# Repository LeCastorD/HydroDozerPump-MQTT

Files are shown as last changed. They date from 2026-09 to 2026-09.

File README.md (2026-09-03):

<div align="center">
  <h1>HydroDozerPump MQTT</h1>
  <p><strong>ESP8266 two-pump hydroponic dosing controller for Home Assistant</strong></p>
  <table>
    <tr>
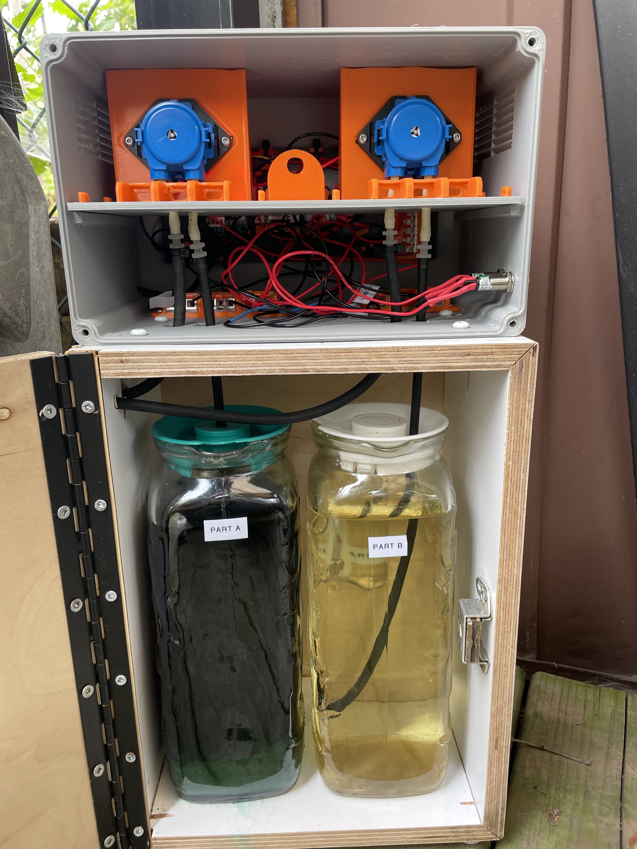
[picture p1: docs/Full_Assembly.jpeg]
Complete HydroDozerPump assembly with enclosure, two Kamoer pumps, and nutrient bottles
      <td align="center"><br><em>Complete HydroDozerPump assembly</em></td>
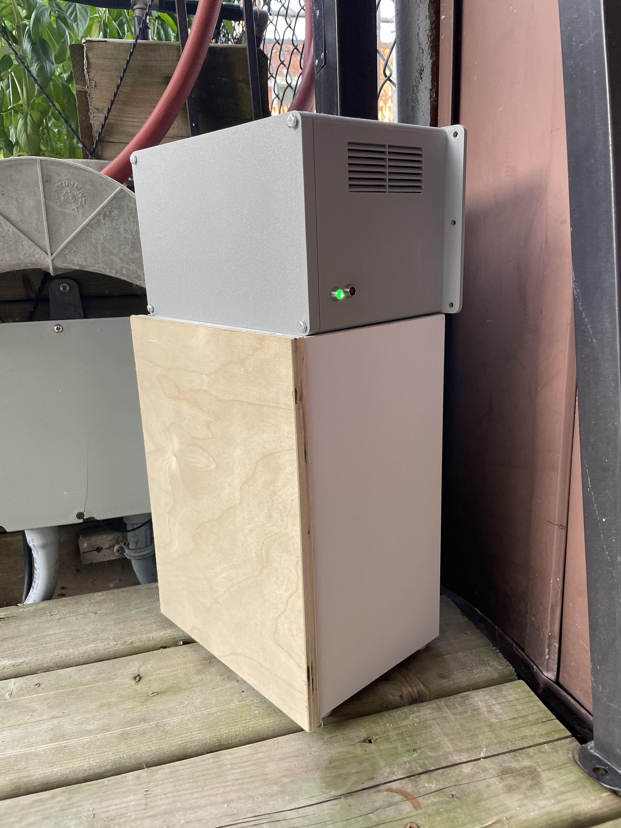
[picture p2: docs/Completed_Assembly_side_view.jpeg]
Side view of the completed HydroDozerPump enclosure with green and red status lights
      <td align="center"><br><em>Completed enclosure side view</em></td>
    </tr>
    <tr>
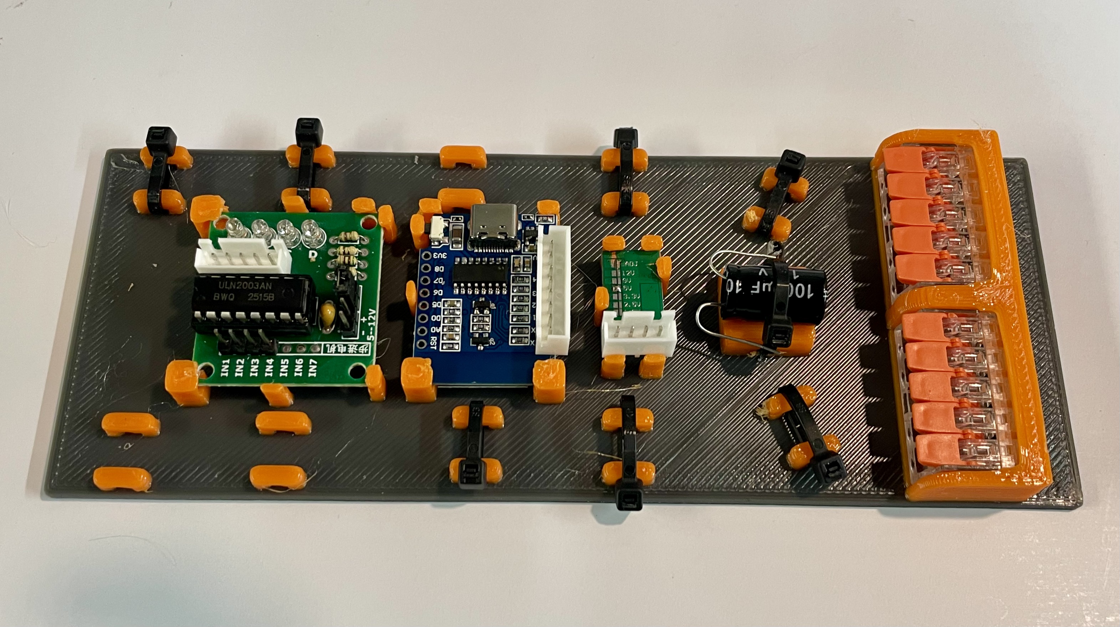
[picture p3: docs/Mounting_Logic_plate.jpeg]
Populated HydroDozerPump logic mounting plate with controller, ULN2003 board, and power terminals
      <td align="center"><br><em>Populated logic mounting plate</em></td>
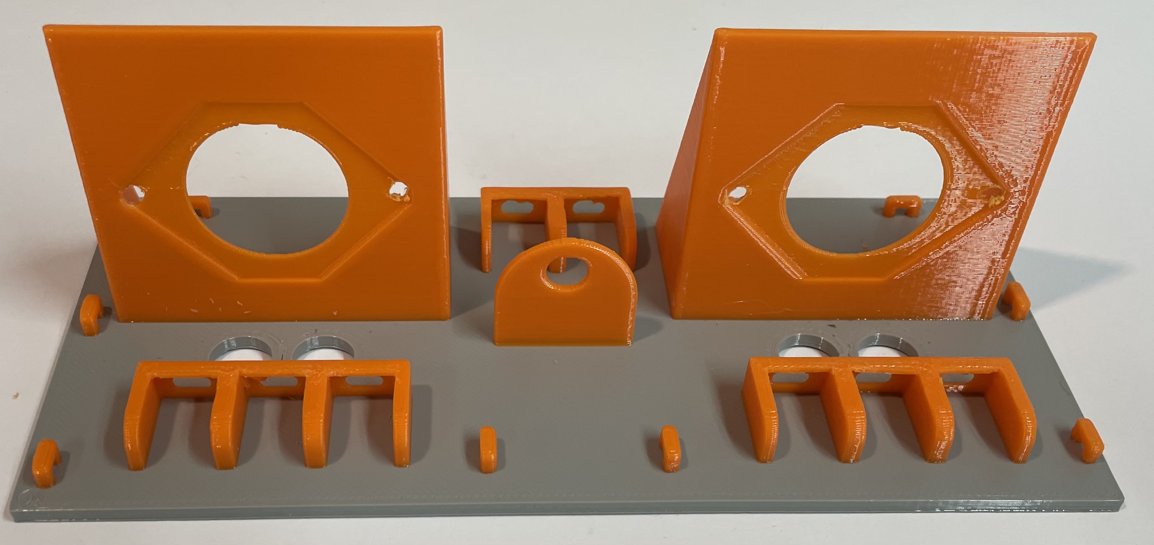
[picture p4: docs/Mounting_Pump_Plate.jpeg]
HydroDozerPump pump mounting plate and printed pump brackets
      <td align="center"><br><em>Pump mounting plate and brackets</em></td>
    </tr>
  </table>
  <p>
    <a href="#build-with-platformio">Build</a> |
    <a href="#wiring">Wiring</a> |
    <a href="#enclosure-and-assembly">Enclosure</a> |
    <a href="#first-setup">First setup</a>
  </p>
</div>

> Remaining image placeholder: the validated wiring drawing will be added after the reference image is available.

<h2 id="table-of-contents">Table of Contents</h2>

<ul>
  <li><a href="#overview">Overview</a></li>
  <li><a href="#typical-usage">Typical usage</a></li>
  <li><a href="#features">Features</a></li>
  <li><a href="#hardware">Hardware</a></li>
  <li><a href="#component-reference">Component reference</a></li>
  <li><a href="#device-naming">Device naming</a></li>
  <li><a href="#safety">Safety</a></li>
  <li><a href="#wiring">Wiring</a></li>
  <li><a href="#status-indicator-lights">Status indicator lights</a></li>
  <li><a href="#bill-of-materials">Bill of materials</a></li>
  <li><a href="#enclosure-and-assembly">Enclosure and assembly</a></li>
  <li><a href="#build-with-platformio">Build with PlatformIO</a></li>
  <li><a href="#upload-firmware">Upload firmware</a></li>
  <li><a href="#ota-upgrade">OTA upgrade and LittleFS data</a></li>
  <li><a href="#initial-wi-fi-configuration">Initial Wi-Fi configuration</a></li>
  <li><a href="#default-web-ui-login">Default Web UI login</a></li>
  <li><a href="#first-setup">First setup</a></li>
  <li><a href="#pump-calibration-and-dosing">Pump calibration and dosing</a></li>
  <li><a href="#web-ui-reference">Web UI reference</a></li>
  <li><a href="#home-assistant-interface">Home Assistant interface</a></li>
  <li><a href="#security">Security</a></li>
  <li><a href="#repository-layout">Repository layout</a></li>
  <li><a href="#license">License</a></li>
  <li><a href="#disclaimer">Disclaimer</a></li>
</ul>

<h2 id="overview">Overview</h2>

<p>HydroDozerPump is a two-channel hydroponic dosing controller built around a Wemos D1 Mini (ESP8266). It drives Pump A and Pump B through an external driver, tracks the remaining volume in two nutrient bottles, and publishes its state and controls through MQTT discovery for Home Assistant.</p>

<blockquote>
  <p><strong>Beta / experimental hardware:</strong> this project is in beta and the current enclosure does not provide the wet/dry separation planned for a production design. It does not claim compliance with <a href="https://www.ul.com/services/environmental-rated-accessories-enclosures">ANSI/UL 50E</a>, <a href="https://www.nema.org/docs/default-source/standards-document-library/nema-250-2018-contents-and-scope.pdf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">NEMA 250</a>, <a href="https://webstore.iec.ch/en/publication/2448">IEC 60529</a>, or, where applicable, <a href="https://docinfofiles.nfpa.org/files/AboutTheCodes/70/70_A2022_NEC_P07_FD_PIReport_rev_1005.pdf">ANSI/NFPA 70 (NEC), Article 547</a>.</p>
</blockquote>

<p>The controller supports manual doses, per-pump calibration, three daily scheduler slots, bottle refill tracking, pump-run logging, browser-based configuration, and OTA firmware updates. It is intended for low-voltage dosing hardware only; select and wire the pump power supply and driver for the exact pumps in the installation.</p>

<p><strong>Wi-Fi limitation:</strong> the ESP8266 supports 2.4 GHz 802.11 b/g/n Wi-Fi only. Use a compatible 2.4 GHz network for onboarding and normal operation.</p>

<h2 id="typical-usage">Typical usage</h2>

<ol>
  <li>Connect the controller to Wi-Fi, configure MQTT, and confirm that the MQTT Settings page reports a connection and Home Assistant discovers the device.</li>
  <li>Route each pump outlet to a safe test container, verify the flow direction, then calibrate Pump A and Pump B using the measured volume.</li>
  <li>Measure each nutrient container's usable volume and enter the capacity for the matching bottle in Home Assistant.</li>
  <li>Set the total daily dose and the Pump A/Pump B ratio, then schedule the three dosing times for the required photoperiod.</li>
  <li>Confirm the first doses and bottle-volume tracking, then refill and reset bottle volumes as needed.</li>
</ol>

<h2 id="features">Features</h2>

<ul>
  <li>Two independently controlled dosing pumps with active-high driver outputs</li>
  <li>Two tracked nutrient bottles with capacity, remaining volume, and low-bottle alarm state</li>
  <li>Per-pump flow calibration and measured-volume dosing</li>
  <li>Three daily scheduler slots with a pause control and a delay between Pump A and Pump B</li>
  <li>WiFiManager onboarding, DHCP or static network settings, and mDNS</li>
  <li>MQTT state publishing and Home Assistant MQTT discovery</li>
  <li>Web UI for configuration, calibration, backups, pump logs, and safe MQTT commands</li>
  <li>LittleFS storage for configuration and pump-run logs</li>
  <li>OTA firmware updates and a hardware factory-reset input</li>
</ul>

<h2 id="hardware">Hardware</h2>

<ul>
  <li>Wemos D1 Mini or compatible ESP8266 board</li>
  <li>Two Kamoer peristaltic dosing pumps</li>
  <li>ULN2003 driver board</li>
  <li>LMNIL-775P-12V-G and LMNIL-775P-12V-R 12 V panel-mount indicator lights</li>
  <li>Power supply sized for the controller and the selected pumps</li>
  <li>Enclosure, wiring, and connectors appropriate for the installation</li>
</ul>

<p>See <a href="docs/BOM.md">docs/BOM.md</a> for the current parts reference and items that still need model-specific confirmation.</p>

<h2 id="component-reference">Component reference</h2>

<p>The following generic reference photos show the controller, power, and wiring hardware used in this type of low-voltage enclosure build. Confirm the ratings and pin labels of the exact parts used in the installation.</p>

<table>
  <tr>
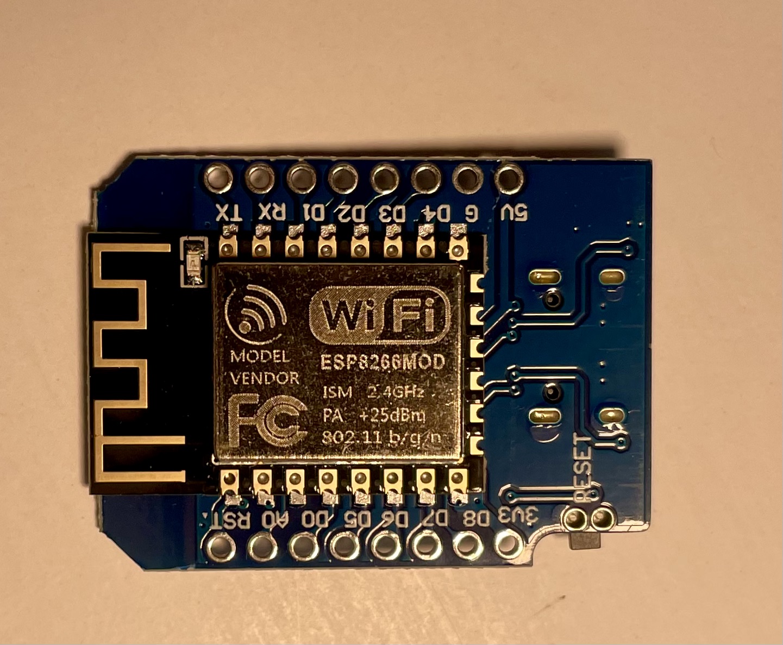
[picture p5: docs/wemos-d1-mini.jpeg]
Wemos D1 Mini ESP8266 controller board
    <td align="center"><br><em>Wemos D1 Mini controller</em></td>
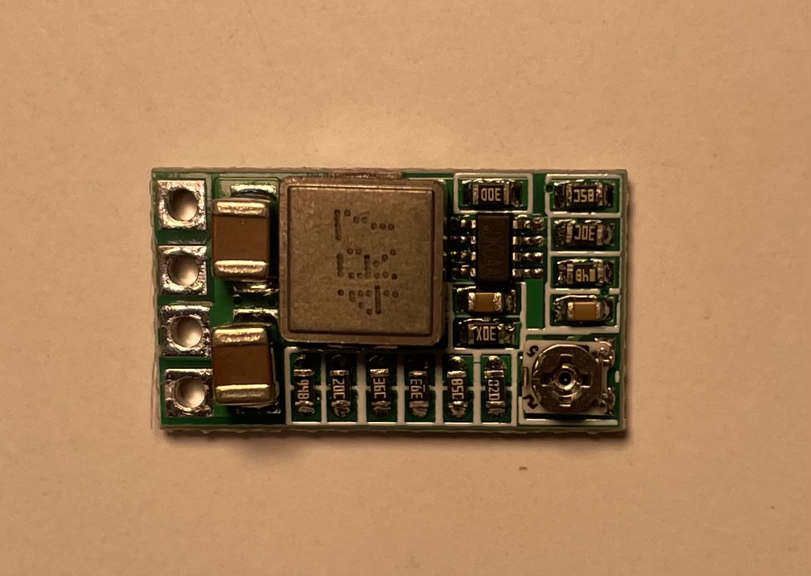
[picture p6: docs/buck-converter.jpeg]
Compact adjustable DC buck converter
    <td align="center"><br><em>Example DC buck converter</em></td>
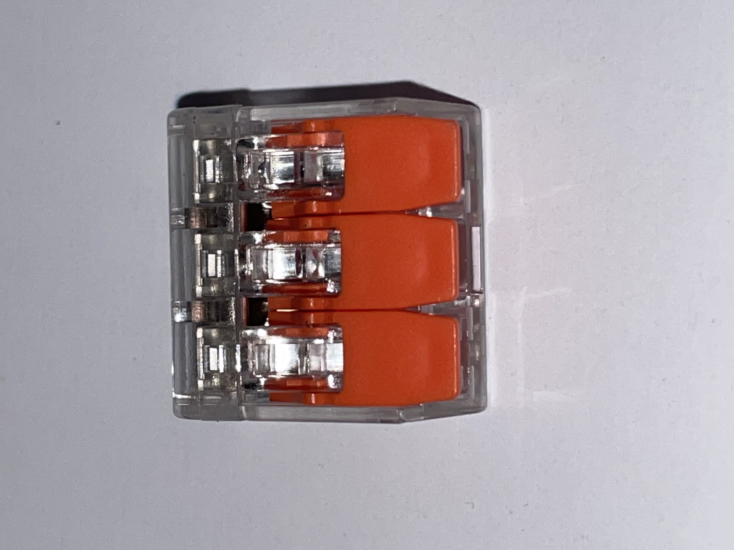
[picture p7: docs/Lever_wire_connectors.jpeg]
Three-position lever wire connector
    <td align="center"><br><em>Lever wire connector</em></td>
  </tr>
  <tr>
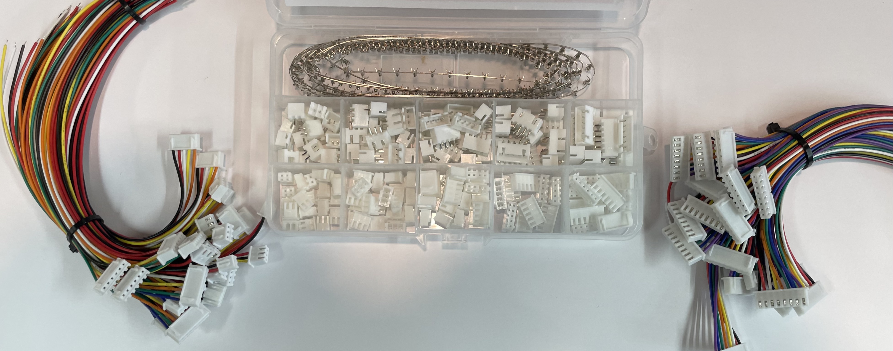
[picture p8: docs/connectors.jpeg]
Connector housings, crimp terminals, and prewired leads
    <td align="center"><br><em>Connector kit and prewired leads</em></td>
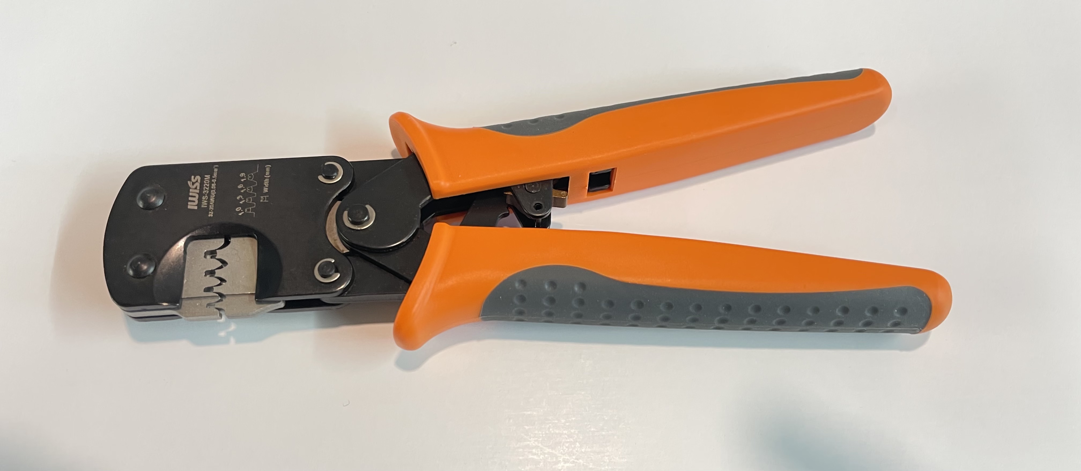
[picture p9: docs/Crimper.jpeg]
Crimping tool for small connector terminals
    <td align="center"><br><em>Crimping tool</em></td>
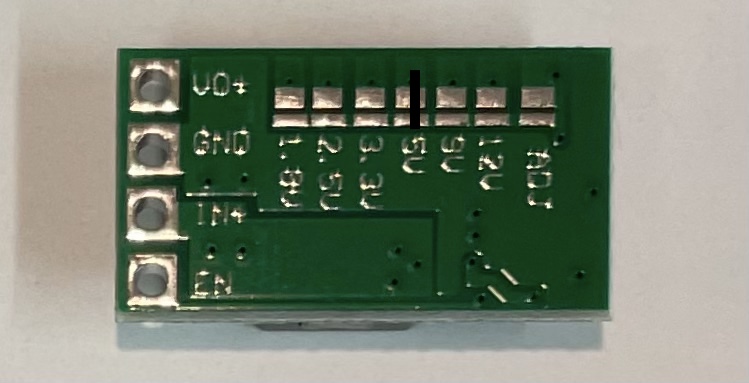
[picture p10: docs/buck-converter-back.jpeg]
Rear view of an example buck converter board
    <td align="center"><br><em>Example buck-converter board layout</em></td>
  </tr>
  <tr>
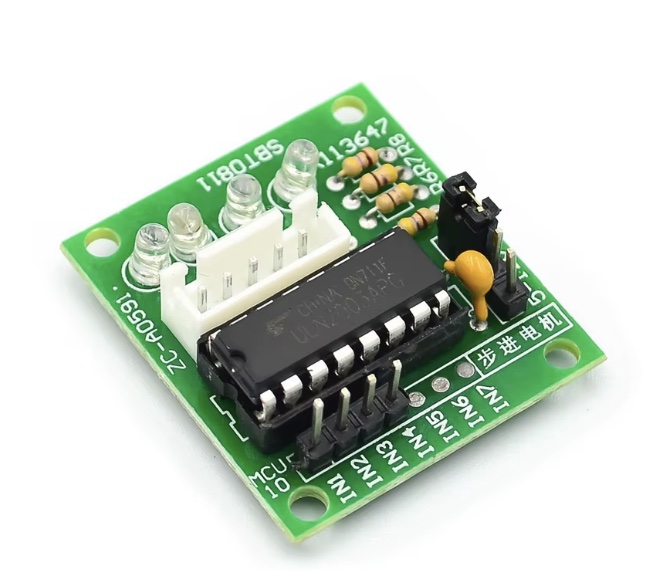
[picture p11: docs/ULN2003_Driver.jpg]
ULN2003 driver board
    <td align="center"><br><em>ULN2003 driver board</em></td>
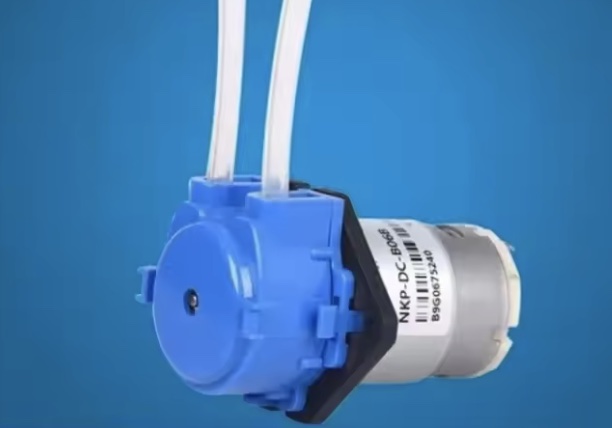
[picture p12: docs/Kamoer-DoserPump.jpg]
Kamoer peristaltic dosing pump with tubing
    <td align="center" colspan="2"><br><em>Kamoer peristaltic dosing pump</em></td>
  </tr>
  <tr>
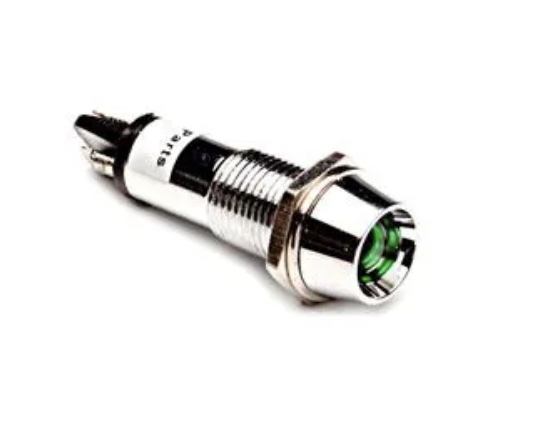
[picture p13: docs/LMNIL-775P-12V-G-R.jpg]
LMNIL-775P-12V green and red panel-mount indicator lights
    <td align="center" colspan="3"><br><em>LMNIL-775P-12V-G / LMNIL-775P-12V-R 12 V status lights</em></td>
  </tr>
</table>

<h2 id="device-naming">Device naming</h2>

<p>When no custom name is saved, the firmware derives a unique identity from the last two bytes of the ESP8266 Wi-Fi MAC address. The generated name uses the form <code>hydrodozerpump-XXXX</code>, where <code>XXXX</code> is a lowercase hexadecimal suffix. The MQTT client ID uses <code>HydroDozerPump-XXXX</code>.</p>

<p>A custom hostname can be saved from <strong>Settings &gt; Networking</strong>. It becomes the Wi-Fi hostname, mDNS hostname (<code>http://&lt;device-name&gt;.local</code>), and the node segment used in the HydroDozerPump MQTT topic tree. The firmware normalizes non-alphanumeric characters in the MQTT node segment to hyphens.</p>

<h2 id="safety">Safety</h2>

<ul>
  <li>Never power a pump or status light from an ESP8266 GPIO pin. Use the ULN2003 driver and a supply sized for every connected load.</li>
  <li>Connect the ESP8266, ULN2003 board, and load power-supply grounds together so the control signals have a common reference.</li>
  <li>Verify pump polarity, driver input logic, tubing, and flow direction with pumps disconnected from nutrient bottles before normal dosing.</li>
  <li>Calibrate each pump with the actual tubing and liquid. Dose accuracy depends on the installed pump, tubing, fluid viscosity, and supply voltage.</li>
  <li>Keep a manual way to stop pump power during commissioning. The firmware hard maximum is not a replacement for safe hardware design and supervision.</li>
</ul>

<h2 id="wiring">Wiring</h2>

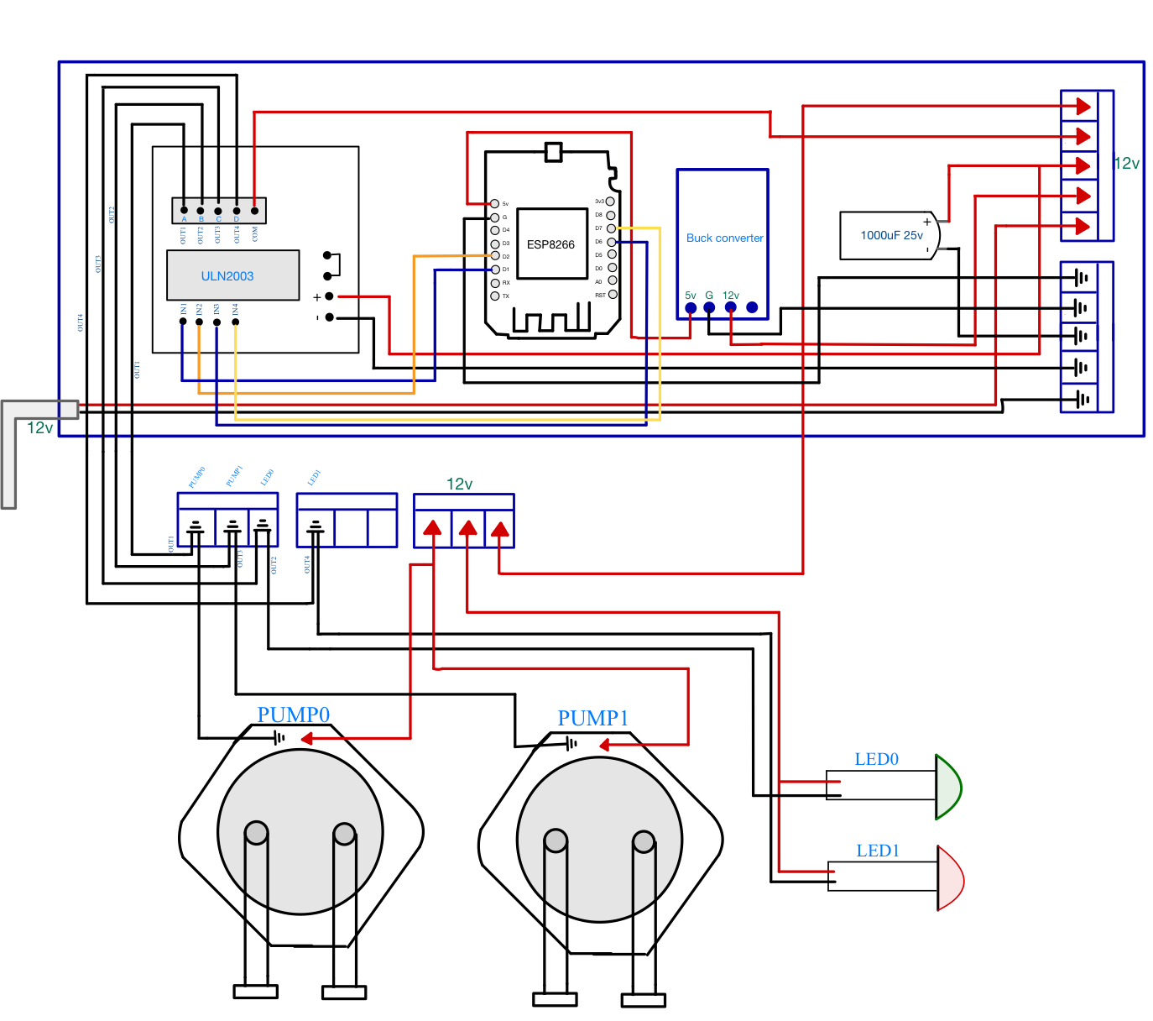
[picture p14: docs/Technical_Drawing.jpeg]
HydroDozerPump technical wiring drawing
<p align="center"><br><em>HydroDozerPump technical wiring reference</em></p>

<table>
  <thead><tr><th>Controller pin</th><th>Connection</th></tr></thead>
  <tbody>
    <tr><td><code>D1</code> / <code>GPIO5</code></td><td>INT1 (<em>ULN2003</em>)</td></tr>
    <tr><td><code>D2</code> / <code>GPIO4</code></td><td>INT2 (<em>ULN2003</em>)</td></tr>
    <tr><td><code>D6</code> / <code>GPIO12</code></td><td>INT3 (<em>ULN2003</em>)</td></tr>
    <tr><td><code>D7</code> / <code>GPIO13</code></td><td>INT1 (<em>ULN2003</em>)</td></tr>
    <tr><td><code>D5</code> / <code>GPIO14</code></td><td>Factory-reset jumper input; short to <code>GND</code> during boot for at least three seconds</td></tr>
    <tr><td><code>GND</code></td><td>Common ground between the ESP8266, ULN2003 board, pumps, status lights, and power supply</td></tr>
  </tbody>
</table>

<p>The firmware assumes active-high pump-driver inputs: <code>HIGH</code> turns a pump on and <code>LOW</code> turns it off. The two status-light outputs are also active-high and use PWM for dimming/pulsing. Change <code>PUMP_ACTIVE_HIGH</code> or <code>STATUS_LED_ACTIVE_HIGH</code> in <a href="src/HydroDozerPump/main.cpp">src/HydroDozerPump/main.cpp</a> only if the installed wiring uses inverted logic. See <a href="docs/hardware-pinout.md">docs/hardware-pinout.md</a> for electrical notes and the recovery-jumper procedure.</p>

<h2 id="status-indicator-lights">Status indicator lights</h2>

<p>The green light is connected through the ULN2003 from <code>D6</code>; the red light is connected from <code>D7</code>.</p>

<table>
  <thead><tr><th>Green</th><th>Red</th><th>State and meaning</th></tr></thead>
  <tbody>
    <tr><td align="center">🟢<br>Solid</td><td align="center">⚫<br>Off</td><td><strong>Normal / idle:</strong> the controller is ready and no pump is currently running.</td></tr>
    <tr><td align="center">🟢<br>Pulsing</td><td align="center">⚫<br>Off</td><td><strong>Pumping:</strong> the green indicator pulses while Pump A or Pump B is running.</td></tr>
    <tr><td align="center">🟢<br>Solid or pulsing</td><td align="center">🔴<br>Solid</td><td><strong>Low bottle:</strong> red turns on when either bottle reaches the configured threshold. Green stays solid while idle and continues pulsing if a pump is running.</td></tr>
    <tr><td align="center">🟢<br>Alternating</td><td align="center">🔴<br>Alternating</td><td><strong>Dosing halted:</strong> green and red alternate every 350 ms when the scheduler is paused or a bottle is empty. Refill the bottle and resume the scheduler before dosing.</td></tr>
  </tbody>
</table>

<p><strong>Priority:</strong> the paused/empty alternating state overrides the normal, pumping, and low-bottle displays.</p>

<h2 id="bill-of-materials">Bill of materials</h2>

<p>See <a href="docs/BOM.md">docs/BOM.md</a> for the electronics, pump-control hardware, wiring, and enclosure parts list.</p>

<h2 id="enclosure-and-assembly">Enclosure and assembly</h2>

<h3>First beta enclosure notice</h3>

<p><strong>This is the first beta release of the mounting and enclosure design.</strong> It is a work in progress. In this revision, the pumps, tubing, and nutrient bottles (the wet side) share the same overall enclosure assembly as the controller, ULN2003 driver, and wiring (the electronics side). It does not provide a tested liquid-tight physical barrier between those areas.</p>

<p>Do not describe this prototype as water-resistant, IP rated, NEMA rated, certified, or compliant with an electrical-enclosure standard. Do not use it unattended or where a leak, condensation, splash, or service activity could reach electronics. Disconnect power before filling bottles, changing tubing, or servicing a pump.</p>

<p>The next enclosure revision is intended to separate the wet side from the electronics using a physical bulkhead and independently managed cable/tube pass-throughs. The finished design will need to be evaluated and tested against the environment and installation requirements that apply to its actual use.</p>

<h3>Standards and design references</h3>

<ul>
  <li><a href="https://www.ul.com/services/environmental-rated-accessories-enclosures">ANSI/UL 50E</a>: environmental considerations for electrical equipment enclosures, including maintaining an environmental seal.</li>
  <li><a href="https://www.nema.org/docs/default-source/standards-document-library/nema-250-2018-contents-and-scope.pdf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">NEMA 250</a>: enclosure types and environmental protection for electrical equipment up to 1000 V.</li>
  <li><a href="https://webstore.iec.ch/en/publication/2448">IEC 60529</a>: IP Code classification for protection provided by electrical enclosures against ingress.</li>
  <li><a href="https://docinfofiles.nfpa.org/files/AboutTheCodes/70/70_A2022_NEC_P07_FD_PIReport_rev_1005.pdf">ANSI/NFPA 70 (NEC), Article 547</a>: relevant where the installation is in an agricultural-building area subject to wet, damp, corrosive, or wash-down conditions.</li>
</ul>

<p>These references do not create a blanket rule that every hydroponic enclosure must use one particular barrier. They establish enclosure-performance and installation expectations; a physical wet/dry separation is the safety approach planned for the next revision. Consult the authority having jurisdiction and a qualified electrical professional for any permanent or mains-connected installation.</p>

<p>The repository includes the current 3MF files:</p>

<ul>
  <li><a href="Enclosure%20and%20mount/Enclosure_Box.3mf">Enclosure_Box.3mf</a></li>
  <li><a href="Enclosure%20and%20mount/Mounting_Llogic_plate.3mf">Mounting_Llogic_plate.3mf</a></li>
  <li><a href="Enclosure%20and%20mount/Mounting_Pump_Plate.3mf">Mounting_Pump_Plate.3mf</a></li>
</ul>

<p>Confirm printed clearances, hardware sizes, pump dimensions, and electrical isolation against the exact components before printing or assembling the enclosure.</p>

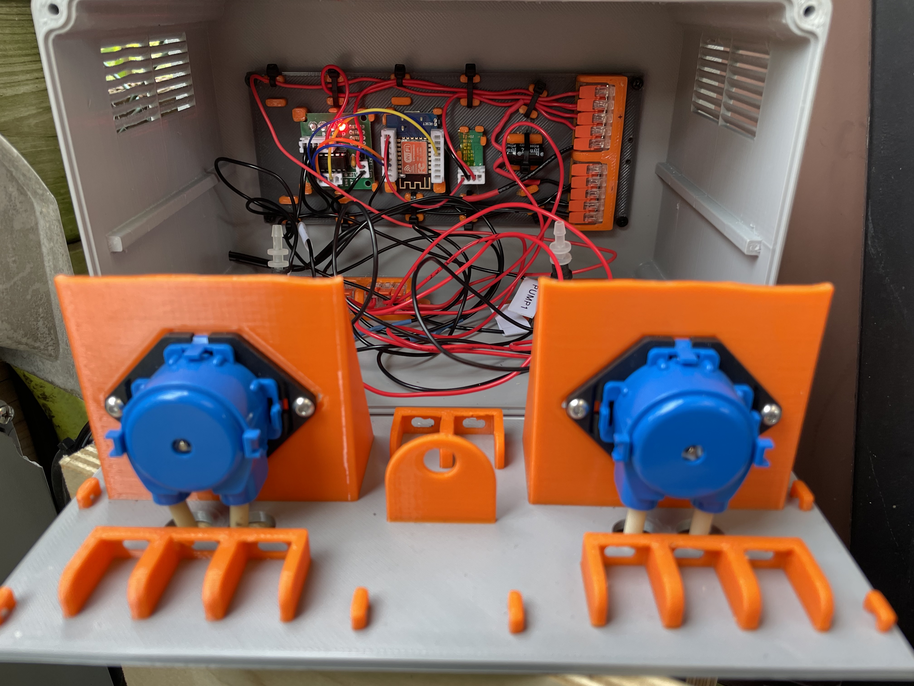
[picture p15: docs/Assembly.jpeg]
HydroDozerPump enclosure assembly with two Kamoer pumps, mounting plates, terminals, and tubing connections
<p align="center"><br><em>Enclosure assembly reference</em></p>

<h2 id="build-with-platformio">Build with PlatformIO</h2>

<h3>Requirements</h3>

<ul>
  <li>VS Code with the PlatformIO extension, or PlatformIO CLI</li>
  <li>A Wemos D1 Mini connected by USB</li>
  <li>The dependencies listed in <a href="platformio.ini">platformio.ini</a></li>
</ul>

<pre><code>pio run</code></pre>

<p>The build target is <code>WEMOS_D1_Mini</code>. The pre-build script updates <code>include/fw_version_auto.h</code>.</p>

<h2 id="upload-firmware">Upload firmware</h2>

<p>Replace <code>&lt;PORT&gt;</code> with the serial port assigned to the board:</p>

<pre><code>pio run -t upload --upload-port &lt;PORT&gt;
pio run -t uploadfs --upload-port &lt;PORT&gt;</code></pre>

<p>The first command uploads the firmware. The second uploads the LittleFS web interface and filesystem data stored in <code>data/web/</code>.</p>

<h2 id="ota-upgrade">OTA upgrade and LittleFS data</h2>

<p><strong>Important:</strong> firmware and LittleFS are separate flash areas. A firmware-only OTA update normally preserves the saved configuration and pump log. Uploading a LittleFS image replaces the filesystem, including <code>/config.json</code> and <code>/pump_runs.csv</code>.</p>

<ol>
  <li>Before any LittleFS upload, download <code>config.json</code> and <code>pump_runs.csv</code> from <strong>Settings &gt; Backup &amp; Restore</strong>.</li>
  <li>For a firmware-only OTA update, sign in to the Web UI and open <code>/update</code>. Upload only the firmware <code>.bin</code>, then verify that MQTT reconnects.</li>
  <li>After a LittleFS upload, restore the backed-up <code>config.json</code> and reboot the controller. Restore <code>pump_runs.csv</code> separately if its history is needed.</li>
  <li>If no backup is restored, configure the controller again, including Wi-Fi, network name, MQTT settings, time zone, credentials, bottle capacities, pump flow values, and scheduler settings.</li>
</ol>

<h2 id="initial-wi-fi-configuration">Initial Wi-Fi configuration</h2>

<p>This project uses <a href="https://github.com/tzapu/WiFiManager">WiFiManager</a> so Wi-Fi credentials are not hard-coded in the firmware.</p>

<ol>
  <li>Power the device with no saved Wi-Fi credentials, or clear them using a factory reset.</li>
  <li>Connect a phone or computer to the temporary access point named <code>HydroDozerPump-Setup</code>.</li>
  <li>Complete the WiFiManager captive portal and save the local 2.4 GHz network credentials.</li>
  <li>After the controller joins the network, open its assigned IP address or mDNS hostname, such as <code>http://hydrodozerpump-ab12.local</code>.</li>
</ol>

<h2 id="default-web-ui-login">Default Web UI login</h2>

<p>The initial Web UI and OTA credentials are case-sensitive:</p>

<table>
  <tr><th>Username</th><td><code>admin</code></td></tr>
  <tr><th>Password</th><td><code>adminpass</code></td></tr>
</table>

<p>Open <code>http://&lt;device-ip&gt;/login</code> when Web UI login is required. Change these values immediately at <strong>Settings &gt; OTA Settings</strong>; the same credentials control both the Web UI login and the <code>/update</code> OTA page. See <a href="docs/security.md">docs/security.md</a>.</p>

<h2 id="first-setup">First setup</h2>

<ol>
  <li><strong>Upload the firmware and Web UI:</strong> upload the firmware, then upload the LittleFS image so the files in <code>data/web/</code> are available on the controller.</li>
  <li><strong>Connect to Wi-Fi:</strong> follow <a href="#initial-wi-fi-configuration">Initial Wi-Fi configuration</a> when no Wi-Fi credentials are saved.</li>
  <li><strong>Set network and time:</strong> in <strong>Settings &gt; Networking</strong>, set the hostname and choose DHCP or static addressing. In <strong>Settings &gt; Time Synchronization</strong>, apply the correct POSIX time-zone string. Accurate time is required for the daily scheduler.</li>
  <li><strong>Secure the device:</strong> replace the Web UI/OTA credentials in <strong>Settings &gt; OTA Settings</strong> and replace the public MQTT defaults in <strong>Settings &gt; MQTT Settings</strong>.</li>
  <li><strong>Connect MQTT:</strong> configure the broker, port, client ID, and a dedicated MQTT account. Confirm that the MQTT page reports a connected state.</li>
  <li><strong>Configure the dosing system:</strong> set bottle capacities, calibrate each pump, set the low-bottle alarm, and configure the schedule before enabling normal dosing.</li>
  <li><strong>Verify Home Assistant:</strong> confirm the MQTT-discovered HydroDozerPump device and controls appear in Home Assistant. The topic contract is documented in <a href="docs/mqtt-contract-v1.md">docs/mqtt-contract-v1.md</a>.</li>
</ol>

<h2 id="pump-calibration-and-dosing">Pump calibration and dosing</h2>

<p>The controller starts with a nominal pump flow of <code>0.9 mL/s</code>; this is only a starting point. Use <strong>Pump Calibration</strong> to run a fixed-duration test, measure the volume dispensed, and save the result for each pump. Recalibrate after changing a pump, tube, liquid, or supply voltage.</p>

<p>The scheduler divides the configured total daily volume across three time slots. Pump A runs first; when both pumps are needed, Pump B runs after the configured safety gap. The scheduler requires valid synchronized time and can be paused from Home Assistant. Bottle volume is reduced after allowed doses and can be reset to the configured capacity using the refill actions.</p>

<h2 id="web-ui-reference">Web UI reference</h2>

> The screenshots below use generic, public-safe example values. Do not publish a device backup or screenshot containing private credentials, hostnames, or network addresses.

<p>The home page provides access to Pump Calibration, Setup, MQTT command sending, Pump Log, Firmware Upgrade, and reboot. The complete route map is maintained in <a href="docs/web-pages-index.md">docs/web-pages-index.md</a>.</p>

<table>
  <tr>
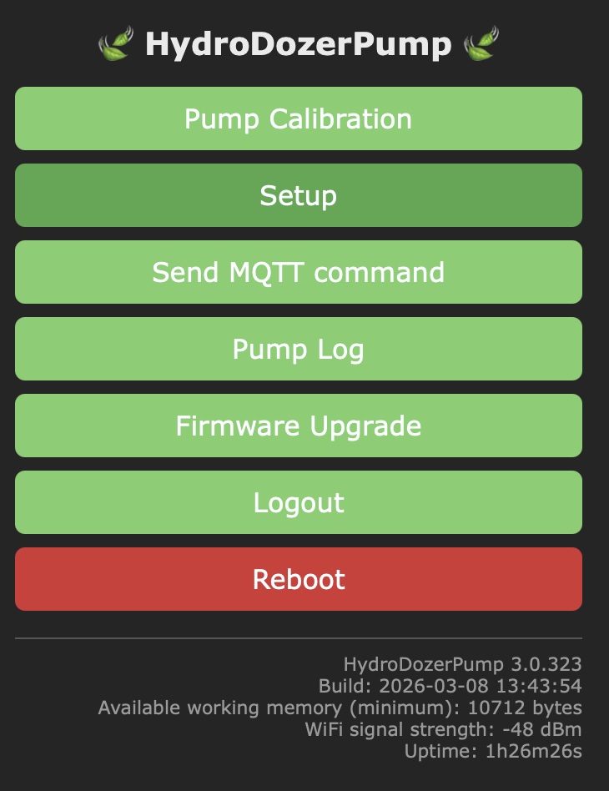
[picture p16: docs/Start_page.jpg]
HydroDozerPump Web UI start page
    <td align="center"><br><em>HydroDozerPump Web UI start page</em></td>
  </tr>
</table>

<h3>Pump calibration</h3>

<p>Select <strong>Calibration Pump A</strong> or <strong>Calibration Pump B</strong> to run that pump for 60 seconds. After it stops, measure the dispensed liquid, enter the measured volume in mL, and select <strong>Apply</strong>. This stores the measured flow rate for future manual and scheduled doses.</p>

<table>
  <tr>
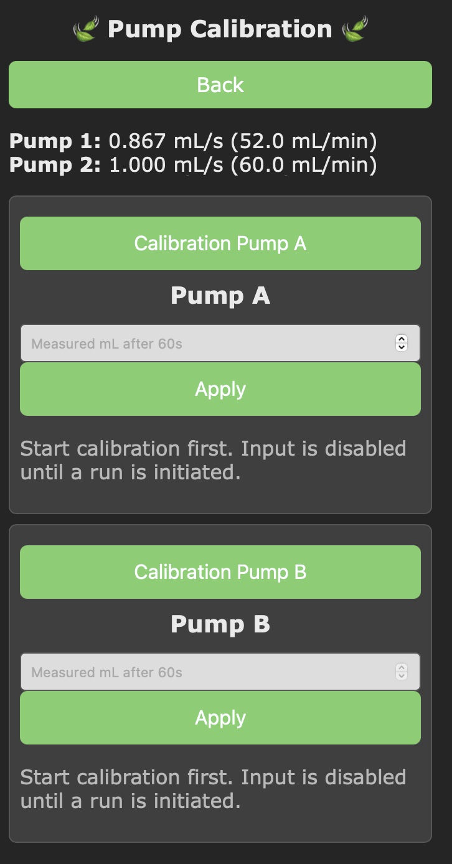
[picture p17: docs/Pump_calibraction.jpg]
HydroDozerPump pump calibration page
    <td align="center"><br><em>Pump calibration for Pump A and Pump B</em></td>
  </tr>
</table>

<h3>Backup and restore</h3>

<p><strong>Download config.json</strong> saves the device configuration, while <strong>Download pump_runs.csv</strong> saves the dosing log. Restore each file only to the matching restore control. A restored <code>config.json</code> can contain credentials, so keep backups private; reboot after restoring configuration. A restored pump log must preserve its CSV header.</p>

<table>
  <tr>
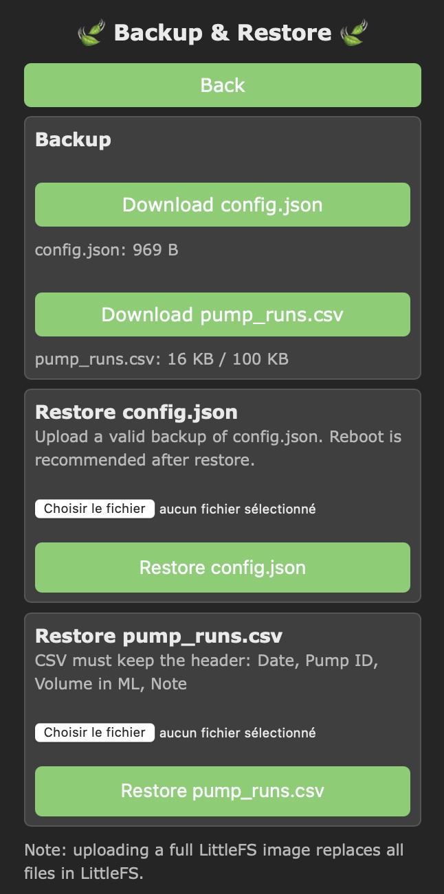
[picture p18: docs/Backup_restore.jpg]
HydroDozerPump backup and restore page
    <td align="center"><br><em>Configuration and pump-log backup and restore</em></td>
  </tr>
</table>

<h3>Pump log</h3>

<p>The pump-log page summarizes the three scheduler slots and shows the newest pump-run entries first. Use <strong>Download Pump Log</strong> to save the CSV file, and <strong>Refresh</strong> to reload the current entries. The log uses the columns <code>Date</code>, <code>Pump ID</code>, <code>Volume in ML</code>, and <code>Note</code>.</p>

<table>
  <tr>
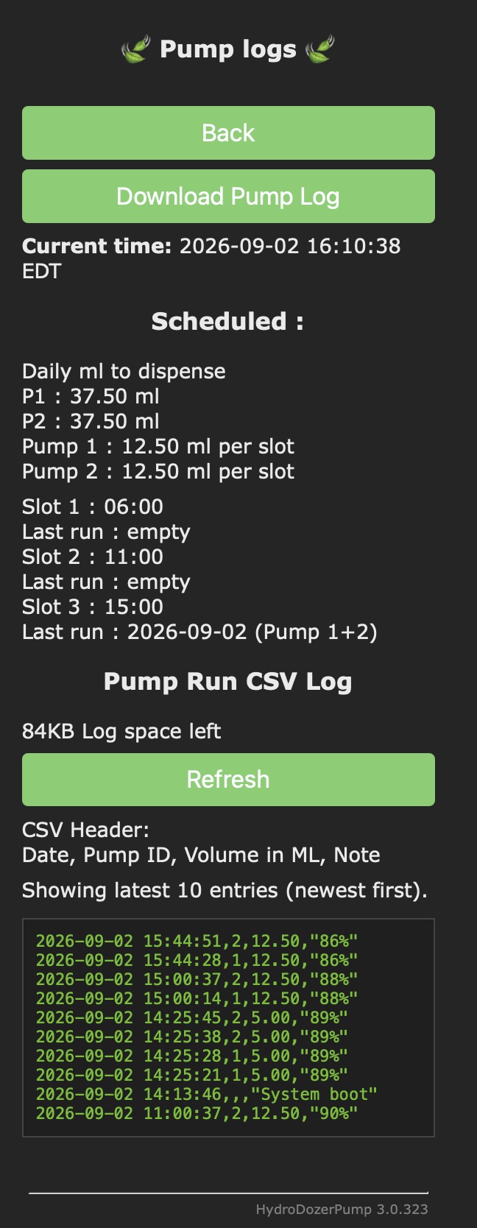
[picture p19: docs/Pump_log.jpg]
HydroDozerPump pump log page
    <td align="center"><br><em>Pump schedule summary and CSV pump-run log</em></td>
  </tr>
</table>

<h3>Firmware upgrade</h3>

<p>Select <strong>Firmware</strong> in the ElegantOTA page to upload the compiled firmware <code>.bin</code>. Select <strong>Filesystem</strong> only when uploading the LittleFS image; it replaces the Web UI and stored files, so back up <code>config.json</code> and <code>pump_runs.csv</code> first.</p>

<table>
  <tr>
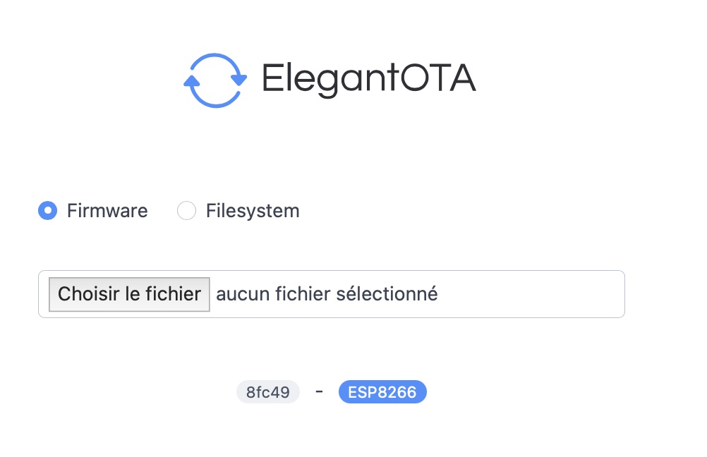
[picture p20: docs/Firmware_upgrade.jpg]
ElegantOTA firmware and filesystem upload page
    <td align="center"><br><em>Firmware and LittleFS upload page</em></td>
  </tr>
</table>

<h3>Send MQTT command</h3>

<p>The sender accepts only the templates shown below and validates the JSON before processing it. Scheduler and capacity templates publish to <code>hydrodozerpump/&lt;node&gt;/ha/cmd</code>; refill templates publish to <code>hydrodozerpump/&lt;node&gt;/cmd</code>. Commands are non-retained. If MQTT is disconnected, a valid command is applied locally and is not published.</p>

<table>
  <tr>
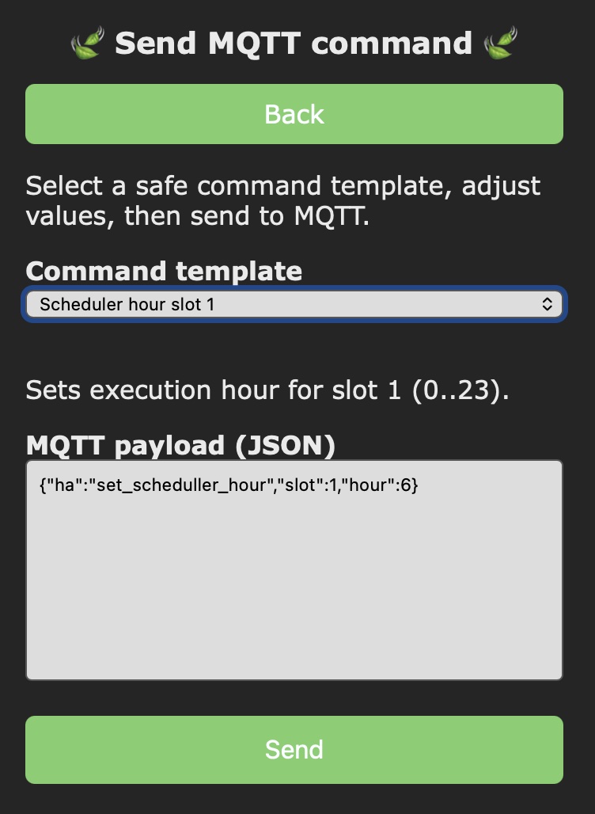
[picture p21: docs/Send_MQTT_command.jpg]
HydroDozerPump Send MQTT command page
    <td align="center"><br><em>Safe MQTT command sender</em></td>
  </tr>
</table>

<table>
  <thead>
    <tr><th>Template</th><th>Accepted value</th><th>Effect</th></tr>
  </thead>
  <tbody>
    <tr><td>Daily total mL</td><td>Positive mL, up to the current safe maximum</td><td>Sets the total liquid scheduled for the day, divided across the three daily slots.</td></tr>
    <tr><td>Part A ratio</td><td>0-100%</td><td>Sets Pump A's share of the daily total and automatically adjusts Part B to make 100%.</td></tr>
    <tr><td>Part B ratio</td><td>0-100%</td><td>Sets Pump B's share of the daily total and automatically adjusts Part A to make 100%.</td></tr>
    <tr><td>Scheduler pause</td><td><code>1</code> pause; <code>0</code> resume</td><td>Stops or resumes scheduled dosing. It does not change the saved schedule.</td></tr>
    <tr><td>Low Bottle Alarm</td><td>0-100%</td><td>Sets the percentage at or below which the low-bottle alarm and red indicator are activated.</td></tr>
    <tr><td>Scheduler hour slot 1</td><td>Hour 0-23</td><td>Sets the execution hour for the first daily dose slot.</td></tr>
    <tr><td>Scheduler hour slot 2</td><td>Hour 0-23</td><td>Sets the execution hour for the second daily dose slot.</td></tr>
    <tr><td>Scheduler hour slot 3</td><td>Hour 0-23</td><td>Sets the execution hour for the third daily dose slot.</td></tr>
    <tr><td>Bottle 1 capacity</td><td>More than 0 and up to 10,000 mL</td><td>Sets Bottle A's capacity. Remaining volume is capped at the new capacity when necessary.</td></tr>
    <tr><td>Bottle 2 capacity</td><td>More than 0 and up to 10,000 mL</td><td>Sets Bottle B's capacity. Remaining volume is capped at the new capacity when necessary.</td></tr>
    <tr><td>Refill Bottle A</td><td>No value</td><td>Sets Bottle A's remaining volume to its configured capacity.</td></tr>
    <tr><td>Refill Bottle B</td><td>No value</td><td>Sets Bottle B's remaining volume to its configured capacity.</td></tr>
  </tbody>
</table>

<h3>MQTT discovery and Home Assistant</h3>

<p>With MQTT discovery enabled, Home Assistant automatically exposes HydroDozerPump controls, bottle information, configuration, and diagnostics. The detailed views below use public-safe example network values.</p>

<table>
  <tr>
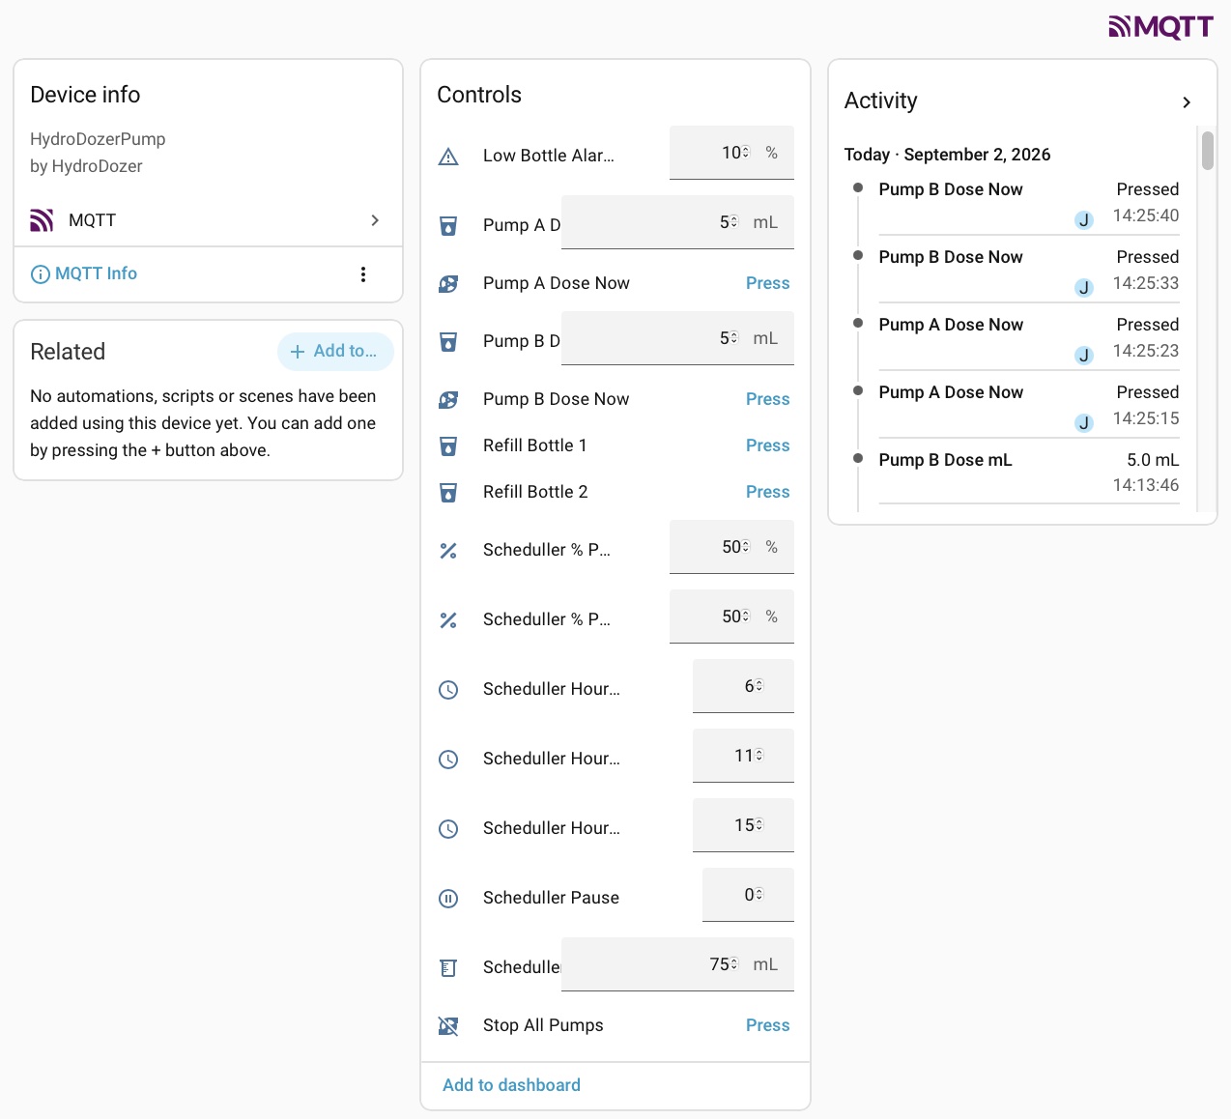
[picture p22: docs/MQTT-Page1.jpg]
Home Assistant MQTT discovery controls for HydroDozerPump
    <td align="center"><br><em>Home Assistant MQTT discovery: controls</em></td>
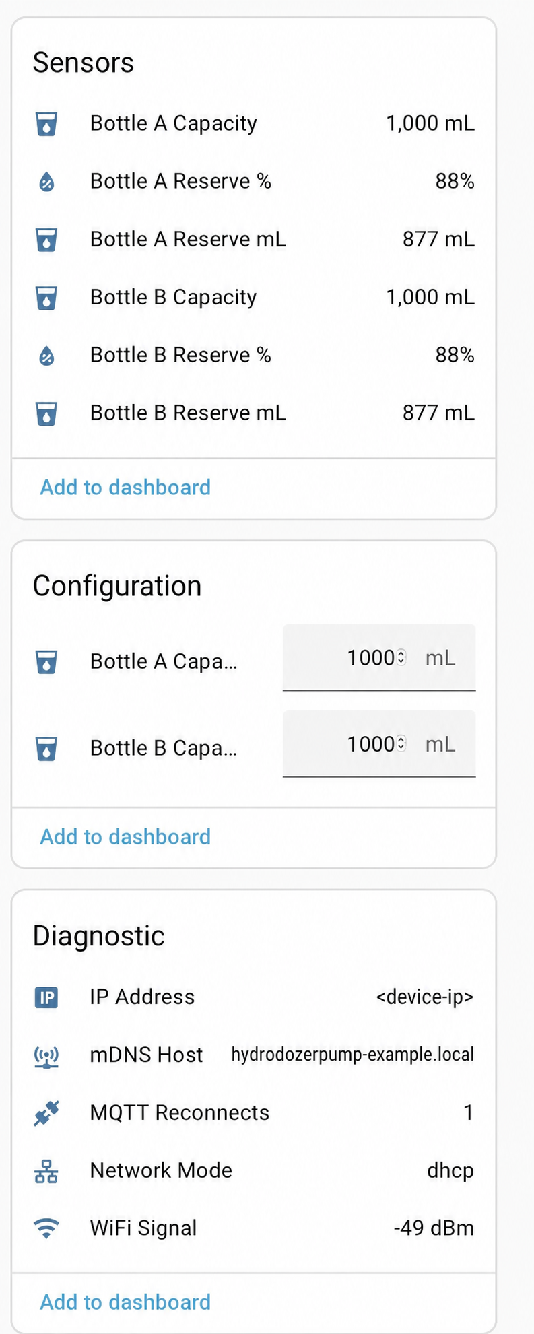
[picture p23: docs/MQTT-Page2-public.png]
Redacted Home Assistant MQTT discovery details for HydroDozerPump
    <td align="center"><br><em>Home Assistant MQTT discovery: configuration and diagnostics</em></td>
  </tr>
  <tr>
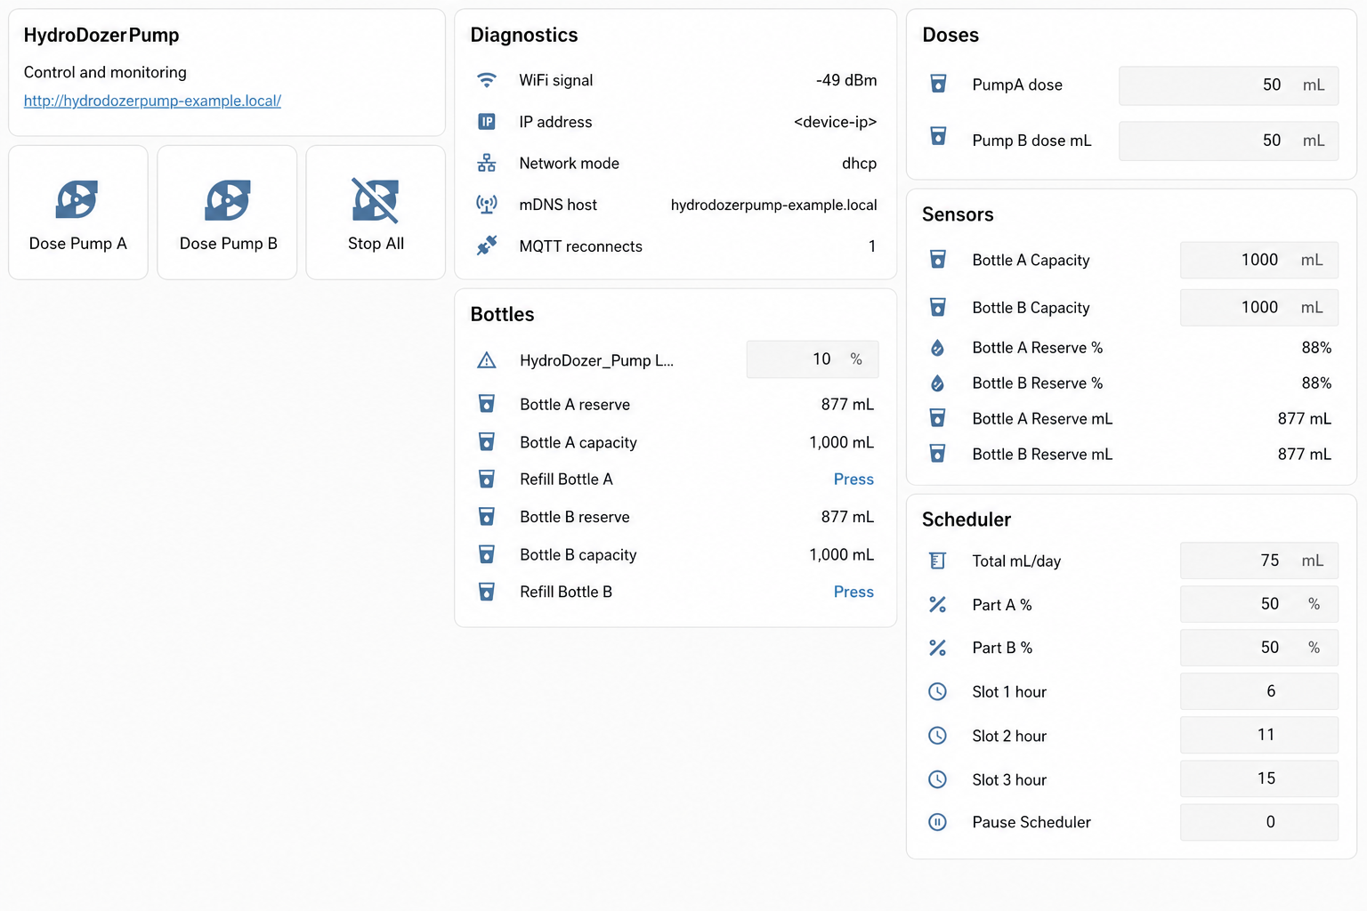
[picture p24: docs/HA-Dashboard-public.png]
Redacted example Home Assistant dashboard for HydroDozerPump
    <td align="center" colspan="2"><br><em>Example HydroDozerPump Home Assistant dashboard</em></td>
  </tr>
</table>

<h3>Network, MQTT, and recovery settings</h3>

<table>
  <tr>
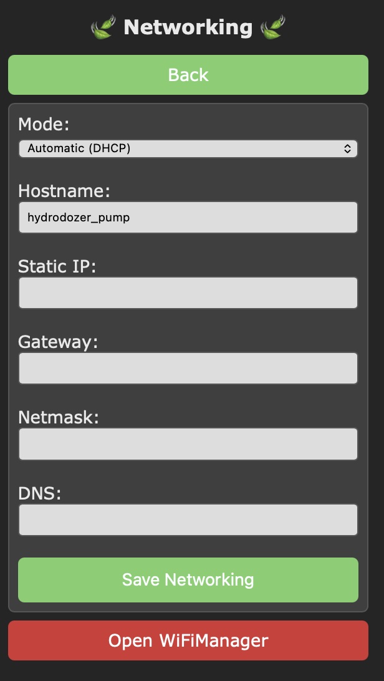
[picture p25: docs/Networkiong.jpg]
HydroDozerPump network settings page
    <td align="center"><br><em>Network settings: DHCP, hostname, and optional static address</em></td>
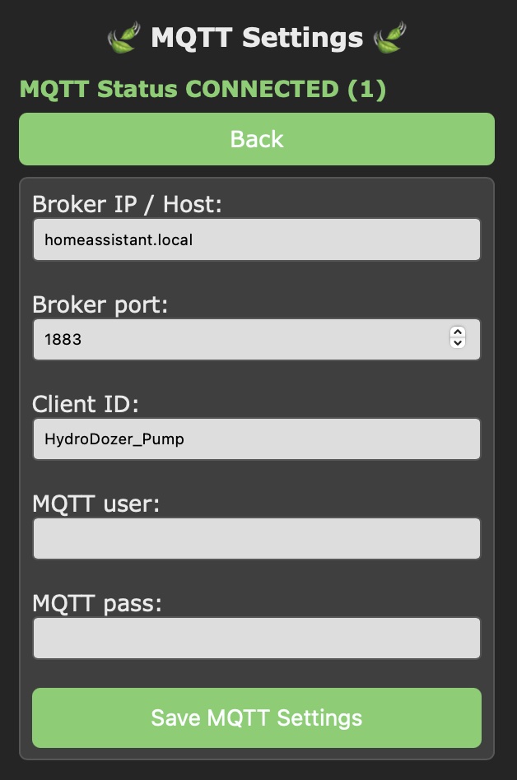
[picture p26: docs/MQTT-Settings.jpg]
HydroDozerPump MQTT settings page
    <td align="center"><br><em>MQTT broker and client settings</em></td>
  </tr>
  <tr>
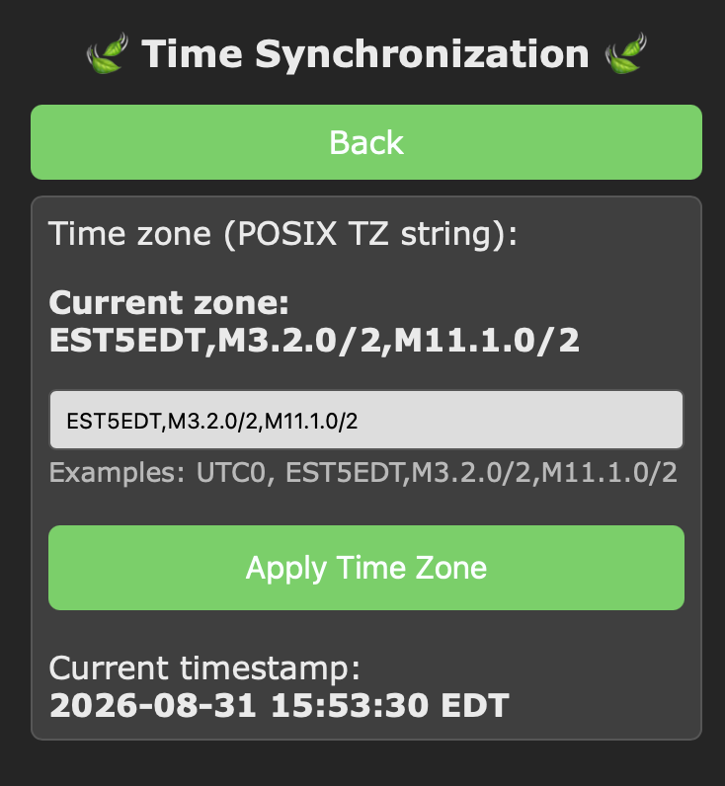
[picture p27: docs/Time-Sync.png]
HydroDozerPump time synchronization settings page
    <td align="center"><br><em>Time Synchronization: <code>/settings/time</code></em></td>
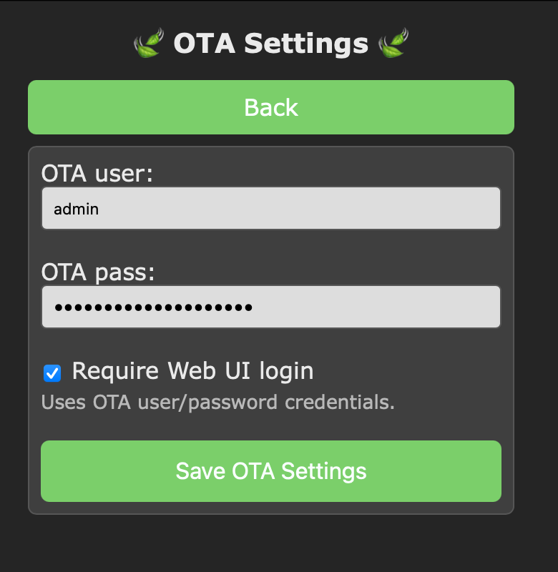
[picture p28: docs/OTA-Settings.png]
HydroDozerPump OTA settings page
    <td align="center"><br><em>OTA Settings: <code>/settings/ota</code></em></td>
  </tr>
  <tr>
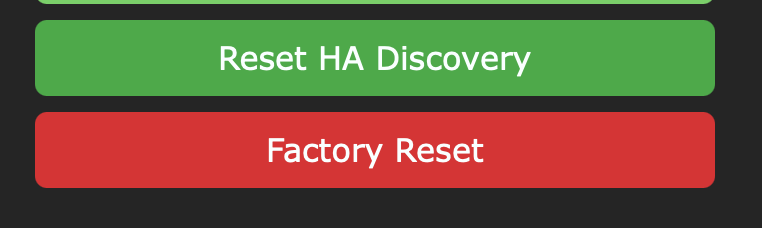
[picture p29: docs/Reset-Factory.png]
HydroDozerPump Home Assistant discovery reset and factory reset controls
    <td align="center" colspan="2"><br><em>Reset controls at the bottom of <code>/settings</code></em></td>
  </tr>
</table>

<p><strong>Factory reset:</strong> the Web UI factory-reset action and the D5 hardware jumper erase Wi-Fi credentials and format LittleFS. This removes the saved configuration, pump log, and Web UI files. Re-upload the LittleFS image before using the Web UI again after a factory reset.</p>

<h2 id="home-assistant-interface">Home Assistant interface</h2>

<p>When MQTT is connected, HydroDozerPump publishes Home Assistant MQTT discovery messages for dosing controls, bottle capacity and reserve values, scheduler controls, alarms, network diagnostics, and pump controls. Home Assistant can issue safe dosing and configuration commands through the discovered entities. Use the documented topic contract when integrating with automations outside Home Assistant.</p>

<h3 id="home-assistant-dashboard">Dashboard template</h3>

<p>The <a href="HA/hydrodozerpump-dashboard.yaml">hydrodozerpump-dashboard.yaml</a> template provides pump controls, scheduler settings, doses, bottle information, and diagnostics for one device.</p>

<ol>
  <li>Confirm MQTT discovery has created the HydroDozerPump device and its entities.</li>
  <li>Copy <code>HA/hydrodozerpump-dashboard.yaml</code> to the Home Assistant configuration directory, then register it as a YAML dashboard in <code>configuration.yaml</code>:</li>
</ol>

<pre><code>lovelace:
  dashboards:
    hydrodozerpump-dashboard:
      mode: yaml
      filename: hydrodozerpump-dashboard.yaml
      title: HydroDozerPump
      icon: mdi:pump
      show_in_sidebar: true</code></pre>

<ol start="3">
  <li>Restart Home Assistant, open the new dashboard, and confirm that every card resolves to an entity.</li>
</ol>

<p><strong>Remap the template before use:</strong> it intentionally uses the placeholder <code>hydrodozerpump_example</code>. In <strong>Settings &gt; Devices &amp; services &gt; Entities</strong>, copy the real IDs created by discovery. A device named <code>hydrodozerpump-ab12</code> may use <code>hydrodozerpump_ab12</code>, but do not assume this: Home Assistant can add a suffix when an ID already exists.</p>

<ul>
  <li>Replace every <code>hydrodozerpump_example</code> occurrence with the confirmed prefix, including both <code>entity:</code> and button <code>target.entity_id</code> values.</li>
  <li>Correct any remaining individual entity IDs from the Entities page; the template's names are examples and may not match your discovered names.</li>
  <li>Replace <code>http://hydrodozerpump-example.local</code> with the controller's actual hostname if you want the dashboard link to work.</li>
  <li>You may freely change card <code>name:</code> values; they are labels only and do not change the entity mapping.</li>
</ul>

<p>See the <a href="https://www.home-assistant.io/dashboards/dashboards/">Home Assistant YAML dashboard documentation</a> for alternative dashboard registration options.</p>

<h2 id="security">Security</h2>

<p>The firmware includes public initial credentials for setup. Change the Web UI/OTA and MQTT defaults before connecting the device to a trusted network or broker. Do not commit a device configuration backup, Wi-Fi password, MQTT password, or OTA password to this repository. See <a href="docs/security.md">docs/security.md</a> for the required changes.</p>

<h2 id="repository-layout">Repository layout</h2>

<pre><code>src/HydroDozerPump/    Firmware source
data/web/              Web interface files stored in LittleFS
docs/                  Hardware, commissioning, MQTT, security, and Web UI documentation
Enclosure and mount/   3D-printable 3MF files
include/               Generated firmware version header
platformio.ini         PlatformIO project configuration</code></pre>

<h2 id="license">License</h2>

<p>This project is licensed under the <a href="LICENSE">MIT License</a>.</p>

<h2 id="disclaimer">Disclaimer</h2>

<p>This project controls pumps and chemical or nutrient dosing. Review, test, and validate the electrical design, calibration, dose limits, and fail-safe behavior before use.</p>

<p>This project was created with the assistance of AI. Review all hardware, firmware, documentation, and safety decisions independently before use.</p>

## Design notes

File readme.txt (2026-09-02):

{"cmd":"dose","pump":1,"ml":5}
{"cmd":"calibrate","pump":1}
{"cmd":"calibrate","pump":1,"measured_ml":54.2}

{"action":"start","pump":1,"duration":5000}
{"action":"stop","pump":1}
{"action":"stop_all"}
{"action":"reboot"}
{"action":"factory_reset"}

{"bottle":1,"set_name":"Nutrient A"}
{"bottle":1,"set_capacity":1500}
{"bottle":1,"refill":true}

{"pump":1,"set_name":"Pump A"}
{"pump":1,"set_bottle_id":2}
{"pump":1,"set_flow_60s":60}

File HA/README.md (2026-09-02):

# Home Assistant Dashboard Template

[`hydrodozerpump-dashboard.yaml`](hydrodozerpump-dashboard.yaml) is a Lovelace dashboard example for one HydroDozerPump device.

The template uses the placeholder device identity `hydrodozerpump_example`. Replace every occurrence with the entity-ID prefix created by Home Assistant for the actual device after MQTT discovery. For example, a device named `hydrodozerpump-ab12` may create entities beginning with `hydrodozerpump_ab12`.

Import the YAML into a manual Home Assistant dashboard only after confirming the discovered entity IDs. Entity names can differ when the device name or Home Assistant discovery identifiers change.

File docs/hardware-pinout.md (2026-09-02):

# HydroDozerPump Hardware Pinout

Board target: Wemos D1 Mini (ESP8266)

## Pin assignments

| Controller pin | ESP8266 GPIO | Firmware role | Connection |
| --- | ---: | --- | --- |
| `D1` | `GPIO5` | Pump A control output | External pump-driver input 1 |
| `D2` | `GPIO4` | Pump B control output | External pump-driver input 2 |
| `D6` | `GPIO12` | Green status-light output | ULN2003 input for the green status light; active-high PWM |
| `D7` | `GPIO13` | Red status-light output | ULN2003 input for the red status light; active-high PWM |
| `D5` | `GPIO14` | Factory-reset input | Jumper or switch to `GND` for recovery |
| `GND` | - | Signal reference | Common ground with ULN2003 board, pumps, status lights, and load supply |

## Pump driver and power

The ESP8266 GPIO pins are control signals only. Do not connect a pump or status light directly to `D1`, `D2`, `D6`, or `D7`. This project uses two Kamoer peristaltic dosing pumps and green/red status lights controlled by a ULN2003 driver board; confirm the board and every connected load's electrical ratings are compatible.

<p align="center">ULN2003 driver board<br><em>ULN2003 driver board reference</em></p>

The firmware currently assumes active-high outputs for the ULN2003 inputs:

- `HIGH` = pump on
- `LOW` = pump off

`D6` and `D7` use active-high PWM for the green and red status lights. The firmware turns the green light on at startup, pulses it while a pump runs, and alternates green/red when dosing is paused or a bottle is empty. The red light indicates a low-bottle alarm during normal operation.

If the installed pump or light wiring is inverted, change `PUMP_ACTIVE_HIGH` or `STATUS_LED_ACTIVE_HIGH` in `src/HydroDozerPump/main.cpp` as applicable. Test all channels with the pump lines disconnected from the nutrient bottles.

Connect the ESP8266 ground, ULN2003 ground, and load power-supply return together. The driver must provide appropriate flyback protection for the load. Keep low-voltage control wires separate from high-current pump wiring where practical and provide strain relief at the enclosure.

## Emergency recovery jumper (`D5`)

`D5` is configured with `INPUT_PULLUP`. To perform a hardware factory reset:

1. Power off the controller.
2. Short `D5` to `GND` with the recovery jumper or switch.
3. Power on and hold the connection for at least three seconds.
4. Remove the jumper and reflash the LittleFS image before returning to the Web UI.

The reset erases Wi-Fi credentials and formats LittleFS. It removes the saved configuration, pump log, and Web UI files. Back up `config.json` and `pump_runs.csv` before using this recovery path whenever possible.

## Caution

- Do not use ESP8266 boot-strap pins for critical outputs or inputs unless the startup behavior is fully understood.
- `D5` is a maintenance/recovery input, not a routine operating control.
- Confirm polarity, supply voltage, and driver compatibility before applying power to the pumps or status lights.

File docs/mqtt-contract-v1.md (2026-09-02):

# HydroDozerPump MQTT Contract v1

Topic namespace base: `hydrodozerpump/<node>/`

`<node>` is the saved device name after MQTT-safe normalization. On a newly flashed device, the firmware generates a name such as `hydrodozerpump-ab12`; the corresponding namespace is `hydrodozerpump/hydrodozerpump-ab12/`.

## 1. Command input topic
- Topic: `hydrodozerpump/<node>/cmd`
- Retain: `false`

### JSON command examples
```json
{"cmd":"dose","pump":1,"ml":5}
{"cmd":"calibrate","pump":1}
{"cmd":"calibrate","pump":1,"measured_ml":54.2}

{"action":"start","pump":1,"duration":5000}
{"action":"stop","pump":1}
{"action":"stop_all"}
{"action":"reboot"}
{"action":"factory_reset"}

{"bottle":1,"set_name":"Nutrient A"}
{"bottle":1,"set_capacity":1500}
{"bottle":1,"refill":true}

{"pump":1,"set_name":"Pump A"}
{"pump":1,"set_bottle_id":2}
{"pump":1,"set_flow_60s":60}
```

### Legacy string commands (compatibility)
- `pump1_on`
- `pump1_off`
- `pump2_on`
- `pump2_off`
- `stop_all`
- `reboot`
- `factory_reset`

## 2. Command ACK/NACK
- Topic: `hydrodozerpump/<node>/cmd/ack`
- Retain: `false`

Example payload:
```json
{"ok":true,"type":"dose","detail":"started","uptime_s":842}
```

Common `type` values:
- `json`
- `bottle_cfg`
- `pump_cfg`
- `cmd`
- `dose`
- `calibrate`
- `action_start`
- `action_stop`
- `action_stop_all`
- `action_reboot`
- `action_factory_reset`
- `legacy_*`

Common `detail` values:
- success: `started`, `stopped`, `updated`, `applied`, `run_started`, `ok`
- errors: `invalid_json`, `unknown_cmd`, `unknown_action`, `invalid_payload`, `invalid_pump_range`, `no_pending_run`, `flow_out_of_range`, `boot_guard`

## 3. Permission topics
- Pump permission:
  - `hydrodozerpump/<node>/pump/1/permission`
  - `hydrodozerpump/<node>/pump/2/permission`
- Bottle permission:
  - `hydrodozerpump/<node>/bottle/1/permission`
  - `hydrodozerpump/<node>/bottle/2/permission`

Permission payload example:
```json
{"pump":1,"bottle":1,"ok":false,"requested_ml":5.0,"remaining_ml":2.1,"percent":21.0,"reason":"not_enough_liquid"}
```

Permission reasons:
- `ok`
- `invalid_pump`
- `invalid_ml`
- `invalid_flow`
- `duration_limit`
- `no_bottle`
- `not_enough_liquid`

## 4. State and telemetry topics
- Availability: `hydrodozerpump/<node>/status`
  - values: `online` / `offline`
  - retained: `true`
- Health: `hydrodozerpump/<node>/health`
  - retained: `true`
  - example:
  ```json
  {"heap":33240,"min_heap":31888,"rssi":-61,"mqtt_reconnects":3}
  ```
- Automatic state: `hydrodozerpump/<node>/auto/state`
  - retained: `true`
  - contains pump state, bottle metrics, scheduler settings, alarms, and network diagnostics
- System state: `hydrodozerpump/<node>/system/state`
  - retained: `true`
  - contains static network, MQTT, and OTA configuration metadata without password values
- Bottle state:
  - `hydrodozerpump/<node>/bottle/1/state`
  - `hydrodozerpump/<node>/bottle/2/state`
  - retained: `true`

## 5. Notes
- Calibration is 2-step:
  1. Start run: `{"cmd":"calibrate","pump":1}`
  2. Submit measured volume after run: `{"cmd":"calibrate","pump":1,"measured_ml":54.2}`
- `action.start` duration is in milliseconds.
- Never publish retained commands on `hydrodozerpump/<node>/cmd`.
- MQTT dangerous commands (`reboot`, `factory_reset`) are blocked during first 60s after boot and ACK with `detail=boot_guard`.
- MQTT `factory_reset` (JSON or legacy string) erases WiFi credentials and formats LittleFS.
- Hardware emergency reset: short `D5` to `GND` at boot for ~3s.
  - This also erases WiFi credentials and formats LittleFS.
- Both reset paths remove `/config.json`, `/pump_runs.csv`, and the LittleFS-hosted Web UI files. Re-upload the LittleFS image before returning to the Web UI.
- Boot-loop troubleshooting guide: `docs/mqtt-boot-loop-troubleshooting.md`

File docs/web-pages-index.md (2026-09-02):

# Web Pages Index (Hierarchy)

Source: `src/HydroDozerPump/main.cpp` (`setupWebServer()` + `setupOTA()`).

## Navigation Tree

```text
/  (Home / Management)
|- /calibration                      (Pump calibration page)
|  |- POST /calibration/start        (Start fixed 60s calibration run)
|  `- POST /calibration/submit       (Submit measured mL and apply flow)
|- /mqtt_send                        (Safe MQTT command sender page)
|  `- POST /mqtt_send_do             (Validate + publish HA command payload)
|- /settings                         (System Settings hub)
|  |- /settings/network              (Networking page)
|  |  |- POST /settings/network_save (Save networking settings)
|  |  `- /wifi_manager               (Open WiFiManager confirmation)
|  |     `- /wifi_manager_do         (Erase WiFi + reboot to setup portal)
|  |- /settings/time                 (Time synchronization page)
|  |  `- POST /settings/time_save    (Apply timezone)
|  |- /settings/mqtt                 (MQTT settings page)
|  |  `- POST /settings/mqtt_save    (Save MQTT settings)
|  |- /settings/ota                  (OTA settings page)
|  |  `- POST /settings/ota_save     (Save OTA credentials)
|  |- /schedule_clear                (Clear scheduler execution history, redirect)
|  |- /ha_discovery_reset            (Reset HA Discovery action/result)
|  `- /factory                       (Factory reset warning page)
|     `- /factory_confirm            (Factory reset action page)
|- /pump_runs_view                   (Pump logs view page)
|  `- /pump_runs_download            (CSV download)
|- /update                           (OTA Firmware Update page, provided by ElegantOTA)
`- /reboot                           (Reboot confirmation)
   `- /reboot_do                     (Reboot action page)
```

## Endpoints by Method

- `GET /` -> Home page with main management actions.
- `GET /calibration` -> Calibration UI for Pump A/B.
- `POST /calibration/start` -> Starts calibration run for selected pump.
- `POST /calibration/submit` -> Saves calibrated flow from measured volume.
- `GET /mqtt_send` -> Safe MQTT command sender UI with template dropdown.
- `POST /mqtt_send_do` -> Validates payload and publishes to `hydrodozerpump/ha/cmd`.
- `GET /settings` -> Settings hub page.
- `GET /settings/network` -> Network settings page.
- `POST /settings/network_save` -> Saves network settings, then redirects.
- `GET /settings/time` -> Time synchronization page.
- `POST /settings/time_save` -> Applies timezone, then redirects.
- `GET /settings/mqtt` -> MQTT settings page.
- `POST /settings/mqtt_save` -> Saves MQTT settings, then redirects.
- `GET /settings/ota` -> OTA settings page.
- `POST /settings/ota_save` -> Saves OTA settings, then redirects.
- `GET /schedule_clear` -> Clears scheduler execution history and redirects to `/settings`.
- `GET /wifi_manager` -> WiFiManager warning/confirmation page.
- `GET /wifi_manager_do` -> Triggers WiFi credential reset + reboot.
- `GET /ha_discovery_reset` -> Sends HA discovery reset (if MQTT connected).
- `GET /pump_runs_view` -> Displays pump log status and log content.
- `GET /pump_runs_download` -> Downloads pump log CSV file.
- `GET /update` -> OTA web updater UI (mounted by `ElegantOTA.begin(&server, ...)`).
- `GET /reboot` -> Reboot confirmation page.
- `GET /reboot_do` -> Reboot action page.
- `GET /factory` -> Factory reset warning page.
- `GET /factory_confirm` -> Factory reset action page.

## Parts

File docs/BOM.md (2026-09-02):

# HydroDozerPump Hardware BOM

<p>
  This bill of materials lists the electronics, pumps, connectors, assembly hardware, and printable parts used by the HydroDozerPump project. Quantities are for one two-pump controller unless noted otherwise. Confirm electrical ratings, connector types, screw sizes, and printed-part fit against the exact components used in the build.
</p>

<h2 id="component-grid">Components</h2>

<table>
  <tr>
    <td valign="top" width="33%">
      <h3>Wemos D1 Mini</h3>
      <p><strong>Quantity:</strong> 1</p>
      <p>ESP8266 controller running the dosing firmware, Web UI, Wi-Fi, MQTT, and Home Assistant discovery.</p>
      <p align="center">Wemos D1 Mini ESP8266 controller board</p>
    </td>
    <td valign="top" width="33%">
      <h3>ULN2003 driver board</h3>
      <p><strong>Quantity:</strong> 1</p>
      <p>Switches the two pump loads and green/red status lights from the ESP8266 control outputs.</p>
      <p align="center">ULN2003 driver board</p>
    </td>
    <td valign="top" width="33%">
      <h3>Kamoer dosing pump</h3>
      <p><strong>Quantity:</strong> 2</p>
      <p>Peristaltic pumps that dispense nutrient Part A and Part B. Calibrate each installed pump separately.</p>
      <p align="center">Kamoer peristaltic dosing pump with tubing</p>
    </td>
  </tr>
  <tr>
    <td valign="top">
      <h3>12 V indicator lights</h3>
      <p><strong>Quantity:</strong> 1 green and 1 red</p>
      <p>LMNIL-775P-12V-G and LMNIL-775P-12V-R panel-mount lights for controller status indication.</p>
      <p align="center">Green and red LMNIL-775P-12V panel-mount indicator lights</p>
    </td>
    <td valign="top">
      <h3>Buck converter</h3>
      <p><strong>Quantity:</strong> 1</p>
      <p>Adjustable DC converter used to provide regulated 5 V for the Wemos. Verify the input range and output setting before connection.</p>
      <p align="center">Adjustable DC buck converter</p>
    </td>
    <td valign="top">
      <h3>Lever wire connectors</h3>
      <p><strong>Quantity:</strong> As required</p>
      <p>Serviceable power-distribution and load wiring connectors. Select connectors rated for the installed pump current.</p>
      <p align="center">Three-position lever wire connector</p>
    </td>
  </tr>
  <tr>
    <td valign="top">
      <h3>JST-XH connector kit</h3>
      <p><strong>Quantity:</strong> 1 kit</p>
      <p>Housings and contacts for controller, pump, and service harnesses. Confirm the chosen pitch and pin count before ordering.</p>
      <p align="center">Connector housings, crimp terminals, and prewired leads</p>
    </td>
    <td valign="top">
      <h3>Prewired connector cables</h3>
      <p><strong>Quantity:</strong> As required</p>
      <p>Prewired and crimped leads for serviceable low-voltage control connections.</p>
      <p align="center">Prewired connector cables and crimp terminals</p>
    </td>
    <td valign="top">
      <h3>Crimping tool</h3>
      <p><strong>Quantity:</strong> 1</p>
      <p>Crimping tool suitable for the selected connector terminals.</p>
      <p align="center">Crimping tool for small connector terminals</p>
    </td>
  </tr>
  <tr>
    <td valign="top">
      <h3>1000 uF, 25 V electrolytic capacitor</h3>
      <p><strong>Quantity:</strong> 1</p>
      <p>Polarized bulk decoupling capacitor for the low-voltage supply rail. Observe polarity and do not exceed the 25 V rating.</p>
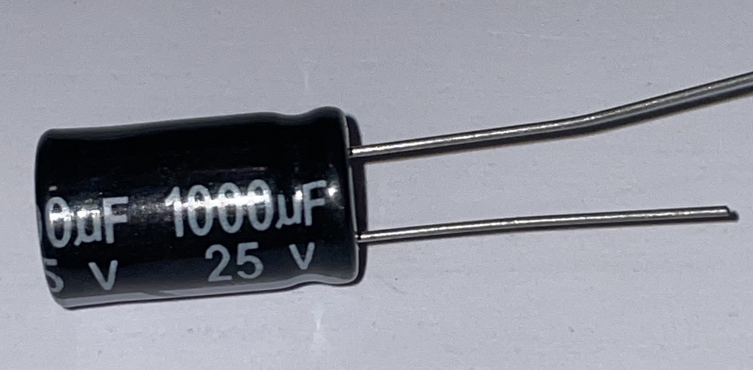
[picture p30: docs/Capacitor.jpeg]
1000 microfarad 25 volt electrolytic capacitor
      
    </td>
    <td valign="top">
      <h3>12 V pump power supply</h3>
      <p><strong>Quantity:</strong> 1</p>
      <p><strong>Model:</strong> <em>TBD</em></p>
      <p>Supply for the pumps, indicator lights, and buck-converter input. Size the current capacity for both pumps and all connected loads.</p>
      <p><em>Reference image placeholder.</em></p>
    </td>
    <td valign="top">
      <h3>Factory-reset jumper or switch</h3>
      <p><strong>Quantity:</strong> 1</p>
      <p>Connects D5 to GND during boot for recovery. Hold for at least three seconds to trigger the factory reset.</p>
      <p><em>Reference image placeholder.</em></p>
    </td>
  </tr>
  <tr>
    <td valign="top" colspan="3">
      <h3>Printable enclosure parts</h3>
      <p><strong>Quantity:</strong> 1 set</p>
      <p>Print the enclosure box, populated logic mounting plate, and pump mounting plate. Confirm the fit against the selected components before final assembly.</p>
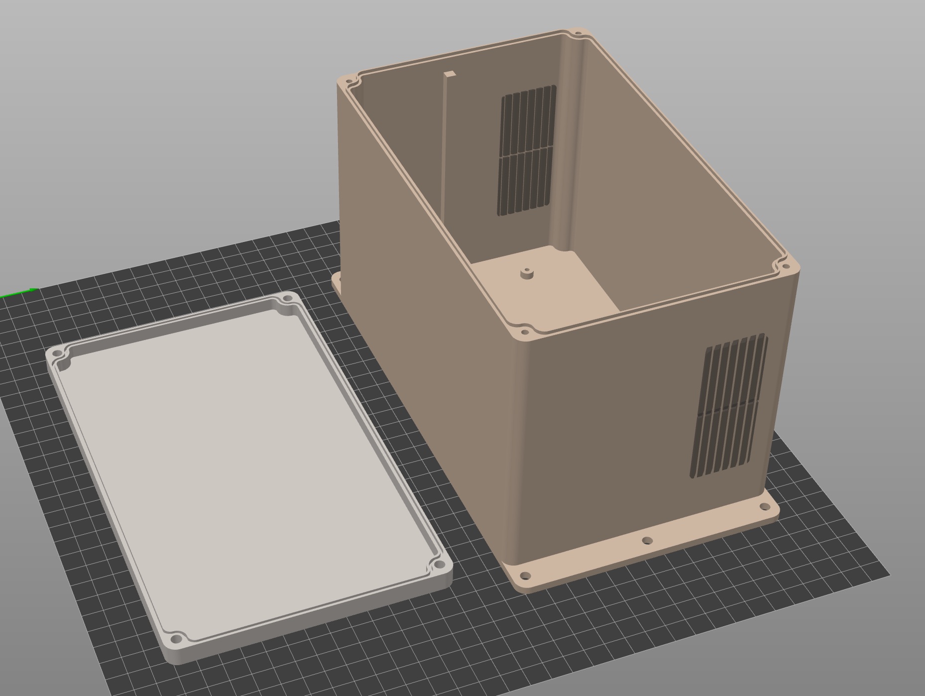
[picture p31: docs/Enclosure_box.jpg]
HydroDozerPump printed enclosure box and lid preview
      <p align="center"><br><em>Enclosure box and lid</em></p>
      <p align="center">HydroDozerPump logic mounting plate<br><em>Logic mounting plate</em></p>
      <p align="center">HydroDozerPump pump mounting plate<br><em>Pump mounting plate</em></p>
      <p><a href="../Enclosure%20and%20mount/Enclosure_Box.3mf">Enclosure_Box.3mf</a><br><a href="../Enclosure%20and%20mount/Mounting_Logic_plate.3mf">Mounting_Logic_plate.3mf</a><br><a href="../Enclosure%20and%20mount/Mounting_Pump_Plate.3mf">Mounting_Pump_Plate.3mf</a></p>
    </td>
  </tr>
</table>

<h2 id="assembly-hardware">Assembly hardware</h2>

<table>
  <thead>
    <tr>
      <th>Hardware</th>
      <th>Quantity</th>
      <th>Use</th>
    </tr>
  </thead>
  <tbody>
    <tr>
      <td>Fasteners and standoffs</td>
      <td><em>TBD</em></td>
      <td>Secure the controller, driver board, pumps, mounting plates, and enclosure panels. Confirm dimensions against the printed parts before ordering.</td>
    </tr>
    <tr>
      <td>Cable ties</td>
      <td>As required</td>
      <td>Harness management and strain relief inside the enclosure.</td>
    </tr>
    <tr>
      <td>Tubing and bottle fittings</td>
      <td><em>TBD</em></td>
      <td>Connect the Kamoer pumps to the nutrient bottles and dosing lines. Match tubing to the installed pump heads and liquids.</td>
    </tr>
    <tr>
      <td>Low-voltage hookup wire</td>
      <td>As required</td>
      <td>Controller, driver, status-light, pump, and power wiring.</td>
    </tr>
  </tbody>
</table>

<h2 id="component-images">Component images</h2>

<p>
  The component cards above contain the available reference images. The image files remain in this folder so they can be reused by the assembly and wiring documentation.
</p>

<h2 id="printable-parts-and-credits">Printable parts and credits</h2>

<table>
  <thead>
    <tr>
      <th>Part or holder</th>
      <th>Source</th>
    </tr>
  </thead>
  <tbody>
    <tr>
      <td>Wemos D1 Mini board holder</td>
      <td><a href="https://www.printables.com/model/48425-wemos-d1-mini-frame-module-for-enclosures-openscad">Printables model 48425</a></td>
    </tr>
    <tr>
      <td>Capacitor holder</td>
      <td><a href="https://www.thingiverse.com/thing:4089178">Thingiverse model 4089178</a></td>
    </tr>
    <tr>
      <td>Generic lever wire connector holder</td>
      <td><a href="https://www.printables.com/model/170622-generic-lever-wire-connector-holder">Printables model 170622</a></td>
    </tr>
    <tr>
      <td>Cable tie holder</td>
      <td><a href="https://github.com/pfliegster/cable-tie-holders">pfliegster/cable-tie-holders</a></td>
    </tr>
    <tr>
      <td>Standoff</td>
      <td><a href="https://www.thingiverse.com/thing:351092">Thingiverse model 351092</a></td>
    </tr>
    <tr>
      <td>Enclosure box</td>
      <td><a href="https://www.printables.com/model/72839-customizable-parametric-stable-and-waterproof-elec">Printables enclosure model 72839</a></td>
    </tr>
  </tbody>
</table>

<h2 id="power-and-wiring-note">Power and wiring note</h2>

<p>
  The power path is <strong>12 V supply &rarr; pumps, status lights, and buck-converter input &rarr; regulated 5 V to the Wemos</strong>. The ESP8266 GPIO pins control the ULN2003 only; they must not power pumps or indicator lights directly. Connect the Wemos, ULN2003, and load power-supply returns to a common ground. See the <a href="hardware-pinout.md">hardware pinout</a> and the <a href="../README.md#wiring">Wiring</a> section for the connection details.
</p>

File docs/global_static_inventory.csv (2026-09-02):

variable_name | purpose | type | size_bytes | description | heap_influence | heap_notes
bottles | SYSTEM | Bottle[3] | 24 | Bottle capacity and remaining values | none | No direct heap allocation
pumpConfig | SYSTEM | PumpConfig[3] | 12 | Per-pump flow calibration values | none | No direct heap allocation
deviceName | SYSTEM | char[32] | 32 | Device hostname and identity label | none | No direct heap allocation
mqttBroker | MQTT | char[40] | 40 | MQTT broker host or IP | none | No direct heap allocation
mqttPort | MQTT | uint16_t | 2 | MQTT broker TCP port | none | No direct heap allocation
mqttClientId | MQTT | char[32] | 32 | MQTT client identifier text | none | No direct heap allocation
mqttUser | MQTT | char[24] | 24 | MQTT authentication username | none | No direct heap allocation
mqttPass | MQTT | char[32] | 32 | MQTT authentication password | none | No direct heap allocation
timeZoneSpec | TIME | char[64] | 64 | POSIX timezone specification string | none | No direct heap allocation
otaUser | OTA | char[24] | 24 | OTA web authentication user | none | No direct heap allocation
otaPass | OTA | char[24] | 24 | OTA web authentication password | none | No direct heap allocation
networkUseDhcp | NETWORK | bool | 1 | DHCP mode enabled flag | none | No direct heap allocation
networkIp | NETWORK | char[16] | 16 | Static IPv4 address text | none | No direct heap allocation
networkGateway | NETWORK | char[16] | 16 | Static gateway IPv4 text | none | No direct heap allocation
networkNetmask | NETWORK | char[16] | 16 | Static netmask IPv4 text | none | No direct heap allocation
networkDns | NETWORK | char[16] | 16 | Static DNS IPv4 text | none | No direct heap allocation
lastMQTTAttempt | MQTT | unsigned long | 4 | Last MQTT reconnect attempt millis | none | No direct heap allocation
MQTT_TOPIC_AVAIL | MQTT | const char* | 4 | Availability topic pointer | none | No direct heap allocation
MQTT_TOPIC_HEALTH | MQTT | const char* | 4 | Health topic pointer | none | No direct heap allocation
MQTT_TOPIC_HEARTBEAT | MQTT | const char* | 4 | Heartbeat topic pointer | none | No direct heap allocation
MQTT_TOPIC_AUTO_STATE | MQTT | const char* | 4 | Auto state topic pointer | none | No direct heap allocation
MQTT_TOPIC_CMD | MQTT | const char* | 4 | Legacy command topic pointer | none | No direct heap allocation
MQTT_TOPIC_HA_CMD | MQTT | const char* | 4 | Home Assistant command topic pointer | none | No direct heap allocation
MQTT_TOPIC_HA_STATUS | MQTT | const char* | 4 | Home Assistant status topic pointer | none | No direct heap allocation
MQTT_TOPIC_CMD_ACK | MQTT | const char* | 4 | Command ack topic pointer | none | No direct heap allocation
MQTT_TOPIC_SYSTEM_STATE | MQTT | const char* | 4 | System state topic pointer | none | No direct heap allocation
MQTT_TOPIC_BOTTLE_STATE_FMT | MQTT | const char* | 4 | Bottle state format topic pointer | none | No direct heap allocation
MQTT_TOPIC_PUMP_DOSE_ML_FMT | MQTT | const char* | 4 | Pump dose format topic pointer | none | No direct heap allocation
MQTT_TOPIC_BOTTLE_PERMISSION_FMT | MQTT | const char* | 4 | Bottle permission format topic pointer | none | No direct heap allocation
MQTT_TOPIC_PUMP_PERMISSION_FMT | MQTT | const char* | 4 | Pump permission format topic pointer | none | No direct heap allocation
MQTT_TOPIC_SCHEDULLER_TOTAL_ML | MQTT | const char* | 4 | Scheduler total topic pointer | none | No direct heap allocation
MQTT_TOPIC_SCHEDULLER_PART_A_PCT | MQTT | const char* | 4 | Scheduler part A topic pointer | none | No direct heap allocation
MQTT_TOPIC_SCHEDULLER_PART_B_PCT | MQTT | const char* | 4 | Scheduler part B topic pointer | none | No direct heap allocation
NTP_SERVER_PRIMARY | TIME | const char* | 4 | Primary NTP server pointer | none | No direct heap allocation
NTP_SERVER_SECONDARY | TIME | const char* | 4 | Secondary NTP server pointer | none | No direct heap allocation
PUMP_RUN_LOG_CSV_PATH | WEB UI | const char* | 4 | CSV log file path pointer | none | No direct heap allocation
pump1 | PUMP | PumpState | 12 | Pump 1 runtime state | none | No direct heap allocation
pump2 | PUMP | PumpState | 12 | Pump 2 runtime state | none | No direct heap allocation
calibrationAwaitResult | CALIBRATION | bool[3] | 3 | Calibration pending flags | none | No direct heap allocation
haDoseMl | HA/MQTT | float[3] | 12 | Last HA dose values | none | No direct heap allocation
schedullerTotalMl | SCHEDULLER | float | 4 | Daily scheduler total ml | none | No direct heap allocation
schedullerPartAPct | SCHEDULLER | float | 4 | Scheduler part A ratio | none | No direct heap allocation
schedullerPartBPct | SCHEDULLER | float | 4 | Scheduler part B ratio | none | No direct heap allocation
schedullerHour1 | SCHEDULLER | int | 4 | Scheduler slot 1 hour | none | No direct heap allocation
schedullerHour2 | SCHEDULLER | int | 4 | Scheduler slot 2 hour | none | No direct heap allocation
schedullerHour3 | SCHEDULLER | int | 4 | Scheduler slot 3 hour | none | No direct heap allocation
schedullerLastRunYear | SCHEDULLER | int[4][3] | 48 | Per slot-pump last run year | none | No direct heap allocation
schedullerLastRunYDay | SCHEDULLER | int[4][3] | 48 | Per slot-pump last run yday | none | No direct heap allocation
schedullerLastAttemptEpoch | SCHEDULLER | time_t[4] | 32 | Per-slot last attempt timestamp | none | No direct heap allocation
schedullerPump2Sequence | SCHEDULLER | SchedullerPump2Sequence | 24 | Queued Pump2 sequence state | none | No direct heap allocation
wm | SYSTEM/WEB UI | WiFiManager | 564 | WiFiManager global object state | high | WiFiManager portal and params allocate heap at runtime
server | WEB UI | ESP8266WebServer | 272 | HTTP server instance object | medium | HTTP request handling uses dynamic String buffers
espClient | MQTT | WiFiClient | 32 | TCP client transport object | low | TCP socket/session buffers allocated by network stack
mqttClient | MQTT | PubSubClient | 76 | MQTT protocol client object | high | PubSubClient mallocs MQTT packet buffer (1024 bytes config)
lastTelemetryTick | SYSTEM/MQTT | unsigned long | 4 | Last health-heartbeat tick millis | none | No direct heap allocation
lastAutoPublish | SYSTEM | unsigned long | 4 | Last auto publish millis | none | No direct heap allocation
lastAutoStatePublishedAt | SYSTEM | unsigned long | 4 | Last auto-state sent millis | none | No direct heap allocation
autoStateDueAt | SYSTEM | unsigned long | 4 | Deferred auto-state due millis | none | No direct heap allocation
haDiscoveryDueAt | MQTT/HA | unsigned long | 4 | Deferred discovery due millis | none | No direct heap allocation
configSaveDueAt | SYSTEM | unsigned long | 4 | Deferred config save due millis | none | No direct heap allocation
nextTimeSyncAt | TIME | unsigned long | 4 | Next NTP sync due millis | none | No direct heap allocation
timeSyncHadValidTime | TIME | bool | 1 | Time validity transition flag | none | No direct heap allocation
minFreeHeap | SYSTEM | uint32_t | 4 | Minimum observed free heap | none | No direct heap allocation
mqttReconnectCount | MQTT | uint32_t | 4 | MQTT reconnect counter | none | No direct heap allocation
haDiscoveryRepublishPending | MQTT/HA | bool | 1 | Discovery republish pending flag | none | No direct heap allocation
autoStatePublishPending | MQTT | bool | 1 | Auto-state publish pending flag | none | No direct heap allocation
haDiscoveryPublishPending | MQTT/HA | bool | 1 | Discovery publish pending flag | none | No direct heap allocation
configSavePending | SYSTEM | bool | 1 | Config save pending flag | none | No direct heap allocation
haDiscoveryStep | MQTT/HA | uint8_t | 1 | Staged discovery step index | none | No direct heap allocation
bottleStatePublishMask | MQTT | uint8_t | 1 | Pending bottle publish bitmask | none | No direct heap allocation
pumpDoseMlPublishMask | MQTT | uint8_t | 1 | Pending dose publish bitmask | none | No direct heap allocation
schedullerStatePublishMask | MQTT | uint8_t | 1 | Pending scheduler publish bitmask | none | No direct heap allocation
mqttInterval | MQTT | const unsigned long (folded) | 0 | MQTT reconnect retry interval | none | No direct heap allocation
MQTT_DANGEROUS_CMD_GUARD_MS | SYSTEM | const unsigned long (folded) | 0 | Dangerous command boot guard | none | No direct heap allocation
autoPublishInterval | MQTT | const unsigned long (folded) | 0 | Periodic auto state interval | none | No direct heap allocation
TIME_SYNC_INTERVAL_MS | TIME | const unsigned long (folded) | 0 | Periodic time sync interval | none | No direct heap allocation
TIME_SYNC_RETRY_MS | TIME | const unsigned long (folded) | 0 | Time sync retry interval | none | No direct heap allocation
TIME_VALID_AFTER_EPOCH | TIME | const time_t (folded) | 0 | Minimum valid system epoch | none | No direct heap allocation
PUMP_RUN_LOG_MAX_BYTES | WEB UI | const size_t (folded) | 0 | CSV max bytes before rotation | none | No direct heap allocation
PUMP1_PIN | PUMP | const uint8_t (folded) | 0 | Pump 1 GPIO pin | none | No direct heap allocation
PUMP2_PIN | PUMP | const uint8_t (folded) | 0 | Pump 2 GPIO pin | none | No direct heap allocation
FACTORY_RESET_PIN | SYSTEM | const uint8_t (folded) | 0 | Factory reset GPIO pin | none | No direct heap allocation
PUMP_ACTIVE_HIGH | PUMP | const bool (folded) | 0 | Pump output active level | none | No direct heap allocation
PUMP_HARD_MAX_MS | PUMP | const unsigned long (folded) | 0 | Pump safety maximum runtime | none | No direct heap allocation
CAL_RUN_DURATION_MS | CALIBRATION | const unsigned long (folded) | 0 | Calibration fixed run duration | none | No direct heap allocation
FACTORY_RESET_HOLD_MS | SYSTEM | const unsigned long (folded) | 0 | Factory jumper hold duration | none | No direct heap allocation
CAL_MIN_FLOW_ML_PER_SEC | CALIBRATION | const float (folded) | 0 | Calibration minimum accepted flow | none | No direct heap allocation
CAL_MAX_FLOW_ML_PER_SEC | CALIBRATION | const float (folded) | 0 | Calibration maximum accepted flow | none | No direct heap allocation
SCHEDULLER_PUMP_SWITCH_GAP_MS | SCHEDULLER | const unsigned long (folded) | 0 | Pump1 to Pump2 gap | none | No direct heap allocation
telemetryInterval | SYSTEM/MQTT | const unsigned long (folded) | 0 | Health and heartbeat interval | none | No direct heap allocation
autoStateMinIntervalMs | MQTT | const unsigned long (folded) | 0 | Auto state minimum spacing | none | No direct heap allocation

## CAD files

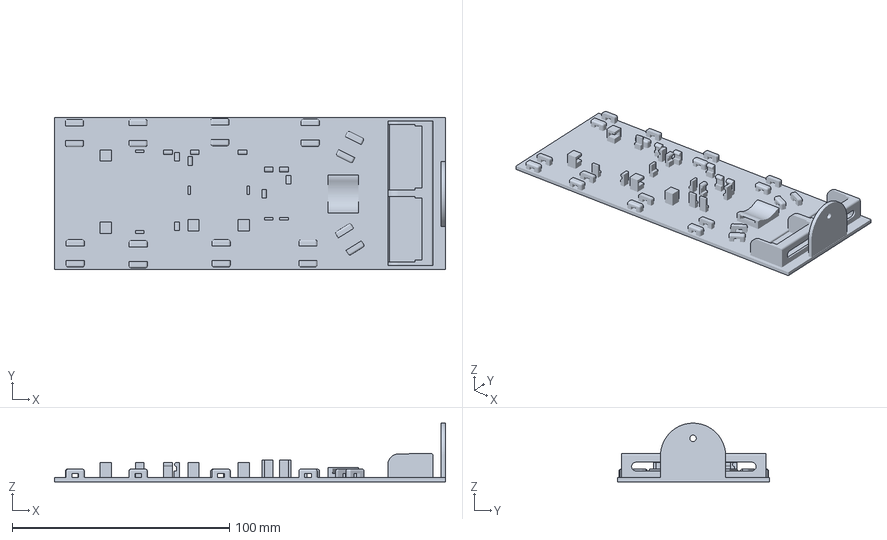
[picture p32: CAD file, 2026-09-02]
Enclosure and mount/Mounting_Logic_plate.3mf
180.0 x 70.0 x 27.0 mm

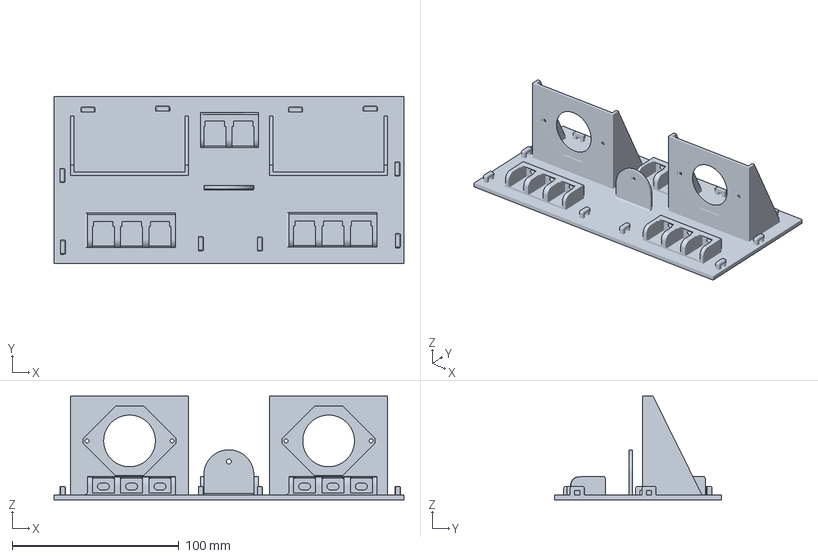
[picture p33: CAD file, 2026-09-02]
Enclosure and mount/Mounting_Pump_Plate.3mf
210.0 x 100.0 x 62.2 mm

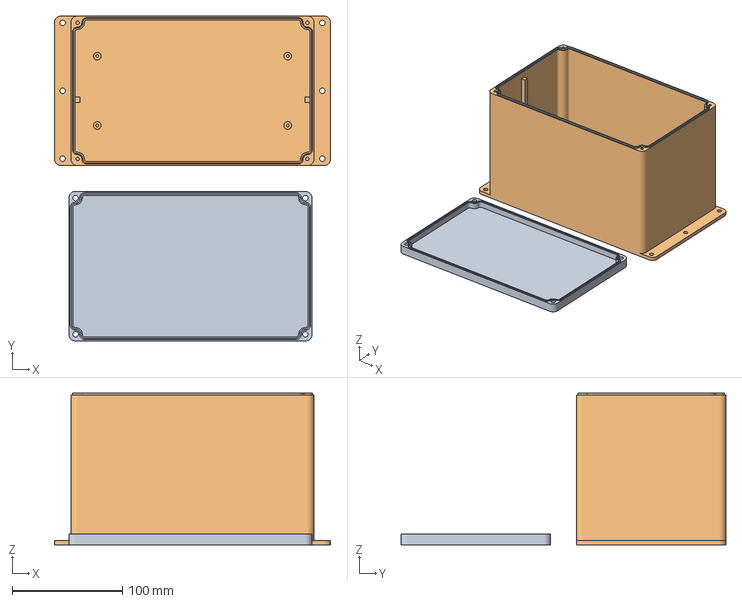
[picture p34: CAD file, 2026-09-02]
Enclosure and mount/Enclosure_Box.3mf
251.0 x 295.3 x 137.7 mm
Top
Merged

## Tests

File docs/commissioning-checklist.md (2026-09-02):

# HydroDozerPump Commissioning Checklist

## 0. Default credentials and connection values
- These are public initial setup values, not secure deployment credentials. Change both the Web UI/OTA and MQTT credentials before connecting the controller to a trusted network or broker. See [Security and Credentials](security.md).
- Web UI login:
  - Username: `admin`
  - Password: `adminpass`
- OTA update login:
  - Username: `admin`
  - Password: `adminpass`
- MQTT defaults in firmware:
  - Broker host: `127.0.0.1`
  - Port: `1883`
  - Username: `homeassistant`
  - Password: `homeassistantpass`

## 1. Change credentials
- In **Settings** > **OTA**, replace the Web UI/OTA username and password with unique credentials.
- In **Settings** > **MQTT**, replace the MQTT username and password with a dedicated broker account.
- Verify the Web UI and `/update` page accept the new Web UI/OTA credentials.
- Verify the controller reconnects to MQTT using the new MQTT credentials.

## 2. Power and wiring
- Verify common ground between ESP8266 and ULN2003.
- Verify pump channels match firmware pins (`D1`, `D2`).
- Power device with pumps disconnected first.

## 3. Network bring-up
- Connect to WiFi via WiFiManager portal.
- Open root page and verify IP, RSSI, and heap visible.
- Confirm hostname resolves (mDNS) if used.

## 4. MQTT connectivity
- Confirm `hydrodozerpump/<node>/status` publishes `online`, using the current device node.
- Confirm command subscription by sending `stop_all`.
- Confirm ACK messages on `hydrodozerpump/<node>/cmd/ack`.

## 5. Bottle and pump config
- Set bottle names and capacities.
- Set pump-to-bottle mapping.
- Set initial flow with `set_flow_60s` if needed.
- Confirm bottle states publish correctly.

## 6. Calibration (per pump)
- Prime tubing to remove air.
- Use production liquid (same viscosity as real use).
- Start calibration run:
  - `{"cmd":"calibrate","pump":1}`
- Measure dispensed volume with a graduated container.
- Submit result:
  - `{"cmd":"calibrate","pump":1,"measured_ml":54.2}`
- Repeat 2-3 times and keep average.

## 7. Dose validation
- Send small test dose:
  - `{"cmd":"dose","pump":1,"ml":5}`
- Verify permission payload and actual dispensed volume.
- Verify remaining bottle volume decreases as expected.

## 8. Safety checks
- Verify `stop_all` always works.
- Verify hard timeout stops pump.
- Verify empty bottle denies dose with clear reason.

## 9. Resilience checks
- Restart broker and verify auto-reconnect.
- Bounce WiFi and verify reconnect.
- Confirm `mqtt_reconnects` increases after recovery.
- Confirm `min_heap` remains stable over time.

## 10. Recovery checks
- Software reset path:
  - Send `{"action":"factory_reset"}` or `factory_reset` on `hydrodozerpump/<node>/cmd`.
  - Verify WiFi credentials are erased and setup portal is available.
  - Verify local filesystem is wiped (config and logs removed).
- Hardware emergency path:
  - Power off device.
  - Place jumper between `D5` and `GND`.
  - Power on and hold jumper for at least 3 seconds.
  - Verify WiFi credentials are erased and local filesystem is wiped.
  - Remove jumper and reboot.

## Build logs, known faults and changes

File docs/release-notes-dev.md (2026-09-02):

# HydroDozerPump Dev Release Notes

Date: 2026-02-16

## Included changes
- JSON command handling hardened with strict type/range validation.
- `set_name` is string-only validation.
- `/stored` page improved with parsed sections and pretty JSON view.
- Calibration implemented as 2-step workflow:
  1. fixed 60s run start
  2. measured volume submit
- System Settings page added:
  - networking hostname
  - DHCP/manual network mode with IP/gateway/netmask/DNS
  - MQTT broker/port/client/user/pass
  - OTA user/pass
  - WiFiManager trigger link
- Runtime config persistence extended in `/config.json` under `system`.
- Setup order fixed so config loads before WiFi/MQTT/OTA init.
- Permission workflow hardened with centralized checks.
- Pump-scoped permission topic added:
  - `hydrodozerpump/pump/%u/permission`
- Command ACK/NACK topic added:
  - `hydrodozerpump/cmd/ack`
- Health and heartbeat telemetry expanded:
  - `min_heap`
  - `mqtt_reconnects`
- Hardware emergency factory reset added:
  - Boot-time jumper on `D5` to `GND` held ~3s
  - Erases WiFi credentials and formats LittleFS
- Factory reset paths unified through shared helper:
  - MQTT and Web UI factory-reset actions format LittleFS
  - The separate WiFiManager reset action keeps its WiFi-only behavior
- MQTT reboot-loop hardening:
  - Dangerous MQTT commands (`reboot`, `factory_reset`) blocked for first 60s after boot
  - ACK detail `boot_guard` returned when blocked
  - Added troubleshooting doc: `docs/mqtt-boot-loop-troubleshooting.md`
- MQTT + Home Assistant auto-publish now functional:
  - New retained state topic: `hydrodozerpump/auto/state` (30s refresh + publish on reconnect)
  - Auto-published fields: all pumps stopped, bottle capacity/percent, network mode, WiFi RSSI, IP, mDNS
  - Home Assistant MQTT discovery configs are now published automatically on MQTT connect

## Compatibility
- Legacy plain-text commands remain supported.
- Existing bottle permission topics remain published when bottle mapping exists.

## Operational notes
- Hostname and manual network changes apply after reboot.
- Invalid manual network values fall back to DHCP at boot.

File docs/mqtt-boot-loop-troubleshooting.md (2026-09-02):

# HydroDozerPump MQTT Boot Loop Troubleshooting

Date: 2026-02-16

## Symptom
- Device repeatedly reboots shortly after connecting to MQTT.
- Serial may show reboot/factory-reset command handling right before restart.

## Root cause (most common)
- A dangerous command is present as a retained MQTT message on `hydrodozerpump/<node>/cmd`.
- After each reconnect, the broker re-delivers the retained command, causing another reboot/reset.

## Firmware protections in place
- Hardware reset jumper check is skipped on software restarts to avoid false factory-reset loops.
- MQTT dangerous command boot guard:
  - For first 60s after boot, MQTT commands `reboot` and `factory_reset` are rejected.
  - Applies to both JSON actions and legacy string commands.
  - ACK detail returned: `boot_guard`.

## Broker-side prevention rules (required)
- Never publish retained commands to `hydrodozerpump/<node>/cmd`.
- In Home Assistant/service automations, explicitly set retain to `false`.
- If retained command was previously sent, clear it once:
  - Publish empty payload with retain=true on `hydrodozerpump/<node>/cmd`.

## Recovery checklist
1. Power-cycle device and watch serial output.
2. Clear retained payload on command topic.
3. Confirm command publishers use retain=false.
4. Send a safe test command (`{"action":"stop_all"}`) and verify ACK.
5. Test `{"action":"reboot"}` only after uptime > 60s.

## Expected ACK behavior
- During first 60s:
  - `{"action":"reboot"}` -> `{"ok":false,"type":"action_reboot","detail":"boot_guard",...}`
  - `{"action":"factory_reset"}` -> `{"ok":false,"type":"action_factory_reset","detail":"boot_guard",...}`
- After 60s:
  - Commands are accepted normally.

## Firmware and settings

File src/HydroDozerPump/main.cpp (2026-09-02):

#include <Arduino.h>
#include <ESP8266WiFi.h>
#include <WiFiManager.h>
#include <ESP8266mDNS.h>
#include <ESP8266WebServer.h>
#include <ElegantOTA.h>
#include <PubSubClient.h>
#include <ArduinoJson.h>
#include <LittleFS.h>
#include <stdarg.h>
#include <ctype.h>
#include <time.h>
#include "fw_version_auto.h"

#ifndef FW_VERSION
#define FW_VERSION "0.0.0-dev"
#endif

#ifndef FW_BUILD_STAMP
#define FW_BUILD_STAMP "unknown"
#endif

#ifndef ENABLE_DEBUG_LOG
#define ENABLE_DEBUG_LOG 0
#endif

#ifndef DEBUG_LOG_BUFFER_SIZE
#define DEBUG_LOG_BUFFER_SIZE 1024
#endif

// --------- bottle concept ------------//

#define DEVICE_NAME_LEN 32
#define MQTT_HOST_LEN 40
#define MQTT_CLIENT_ID_LEN 32
#define MQTT_USER_LEN 24
#define MQTT_PASS_LEN 32
#define OTA_USER_LEN 24
#define OTA_PASS_LEN 24
#define WEB_UI_SESSION_TOKEN_LEN 33
#define IPV4_STR_LEN 16
#define TIMEZONE_LEN 64
#define MQTT_TOPIC_SEGMENT_LEN 32
#define MQTT_TOPIC_BASE_LEN 64
#define MQTT_TOPIC_LEN 96

const char* DEFAULT_DEVICE_NAME_BASE = "hydrodozerpump";
const char* DEFAULT_MQTT_CLIENT_ID_BASE = "HydroDozerPump";

    const char* WEB_UI_BASE_CSS =
        "div,fieldset,input,select{padding:5px;font-size:1em;}"
        ".main{text-align:left;display:inline-block;width:340px;max-width:92vw;color:#eaeaea;box-sizing:border-box;}"
        "fieldset{background-color:#4f4f4f;}p{margin:.5em 0;}"
        "input[type=checkbox],input[type=radio]{width:1em;margin-right:6px;vertical-align:-1px;}"
        "input[type=range]{width:99%;}"
        "input:not([type]),input[type=password],input[type=number]{width:100%;box-sizing:border-box;background:#dddddd;color:#000000;}"
        "select{width:100%;background:#dddddd;color:#000000;block-size:40px;}"
        "textarea{resize:none;width:98%;height:318px;padding:5px;overflow:auto;background:#1f1f1f;color:#65c115;}"
        "body{text-align:center;font-family:verdana,sans-serif;background:#252525;}td{padding:0;}"
        "button,a.button{display:inline-block;text-align:center;border:0;border-radius:.3rem;background:#7bcf6a;color:#faffff;line-height:2.4rem;font-size:1.2rem;width:100%;transition-duration:.4s;cursor:pointer;}"
        "button:hover,a.button:hover{background:#4ea94a;}.bred{background-color:#d43535;}.bred:hover{background-color:#931f1f;}"
        ".bgrn{background-color:#47c266;}.bgrn:hover{background-color:#5aaf6f;}a{text-decoration:none;color:#1fa3ec;}"
        ".p{float:left;text-align:left;}.q{float:right;text-align:right;}.r{border-radius:.3em;padding:2px;margin:6px 2px;}"
        "span{display:inline-block;}h2,h3{text-align:center;}";

    struct Bottle
    {
        float capacity_ml;
        float remaining_ml;
    };

    // Bottles (index 0 unused)
    Bottle bottles[3] = {
        { 0, 0 },
        { 1000.0, 1000.0 },
        { 1000.0, 1000.0 }
    };

    // Pump config: flow only (identity and assignment are fixed by ID).
    struct PumpConfig
    {
        float flow_ml_per_sec;
    };

    PumpConfig pumpConfig[3] = {
        { 0 },
        { 0.9 },
        { 0.9 }
    };

    const char* bottleLabelById(uint8_t bottleId) {
        switch (bottleId) {
            case 1: return "Bottle A";
            case 2: return "Bottle B";
            default: return "Bottle";
        }
    }

    const char* pumpLabelById(uint8_t pumpId) {
        switch (pumpId) {
            case 1: return "Pump A";
            case 2: return "Pump B";
            default: return "Pump";
        }
    }

    uint8_t bottleIdForPump(uint8_t pumpId) {
        if (pumpId >= 1 && pumpId <= 2) return pumpId;
        return 0;
    }

    inline Bottle* getBottleForPump(uint8_t pumpId) {
        uint8_t bid = bottleIdForPump(pumpId);
        if (bid < 1 || bid > 2) return nullptr;
        return &bottles[bid];
    }


// --------- Global constants ------------

    // Device name

    char deviceName[DEVICE_NAME_LEN] = "hydrodozerpump";

    // MQTT Constants

    char mqttBroker[MQTT_HOST_LEN] = "127.0.0.1";
    uint16_t mqttPort = 1883;
    char mqttClientId[MQTT_CLIENT_ID_LEN] = "HydroDozerPump";
    char mqttTopicNode[MQTT_TOPIC_SEGMENT_LEN] = "hydrodozerpump";
    char MQTT_TOPIC_BASE[MQTT_TOPIC_BASE_LEN] = "hydrodozerpump/hydrodozerpump";
    char MQTT_TOPIC_AVAIL[MQTT_TOPIC_LEN] = "hydrodozerpump/hydrodozerpump/status";
    char MQTT_TOPIC_HEALTH[MQTT_TOPIC_LEN] = "hydrodozerpump/hydrodozerpump/health";
    char MQTT_TOPIC_AUTO_STATE[MQTT_TOPIC_LEN] = "hydrodozerpump/hydrodozerpump/auto/state";
    unsigned long lastMQTTAttempt = 0;
    const unsigned long mqttInterval = 5000; // retry every 5 seconds
    const unsigned long MQTT_DANGEROUS_CMD_GUARD_MS = 60000; // ignore reboot/reset commands during first minute after boot
    const unsigned long autoPublishInterval = 60000; // periodic state refresh (60s)
    const unsigned long TIME_SYNC_INTERVAL_MS = 12UL * 60UL * 60UL * 1000UL; // 12h
    const unsigned long TIME_SYNC_RETRY_MS = 60000UL; // retry after 60s when offline
    const time_t TIME_VALID_AFTER_EPOCH = 1704067200; // 2024-01-01 UTC
    const char* NTP_SERVER_PRIMARY = "pool.ntp.org";
    const char* NTP_SERVER_SECONDARY = "time.nist.gov";
    char timeZoneSpec[TIMEZONE_LEN] = "EST5EDT,M3.2.0/2,M11.1.0/2";
    char mqttUser[MQTT_USER_LEN] = "homeassistant";
    char mqttPass[MQTT_PASS_LEN] = "homeassistantpass";
    char otaUser[OTA_USER_LEN] = "admin";
    char otaPass[OTA_PASS_LEN] = "adminpass";
    bool webUiLoginRequired = true;
    char webUiSessionToken[WEB_UI_SESSION_TOKEN_LEN] = "";
    bool networkUseDhcp = true;
    char networkIp[IPV4_STR_LEN] = "";
    char networkGateway[IPV4_STR_LEN] = "";
    char networkNetmask[IPV4_STR_LEN] = "";
    char networkDns[IPV4_STR_LEN] = "";
    // General command topic (legacy + JSON action/cmd).
    char MQTT_TOPIC_CMD[MQTT_TOPIC_LEN] = "hydrodozerpump/hydrodozerpump/cmd";
    // HA-specific control topic used by discovery number/button entities
    // for dosing workflows.
    char MQTT_TOPIC_HA_CMD[MQTT_TOPIC_LEN] = "hydrodozerpump/hydrodozerpump/ha/cmd";
    const char* MQTT_TOPIC_HA_STATUS = "homeassistant/status";
    char MQTT_TOPIC_CMD_ACK[MQTT_TOPIC_LEN] = "hydrodozerpump/hydrodozerpump/cmd/ack";
    char MQTT_TOPIC_SYSTEM_STATE[MQTT_TOPIC_LEN] = "hydrodozerpump/hydrodozerpump/system/state";
    char MQTT_TOPIC_BOTTLE_STATE_FMT[MQTT_TOPIC_LEN] = "hydrodozerpump/hydrodozerpump/bottle/%u/state";
    // Dedicated retained topics keep HA text entities in sync independently
    // from larger JSON payloads.
    char MQTT_TOPIC_PUMP_DOSE_ML_FMT[MQTT_TOPIC_LEN] = "hydrodozerpump/hydrodozerpump/pump/%u/dose_ml";
    char MQTT_TOPIC_BOTTLE_PERMISSION_FMT[MQTT_TOPIC_LEN] = "hydrodozerpump/hydrodozerpump/bottle/%u/permission";
    char MQTT_TOPIC_PUMP_PERMISSION_FMT[MQTT_TOPIC_LEN] = "hydrodozerpump/hydrodozerpump/pump/%u/permission";
    char MQTT_TOPIC_SCHEDULLER_TOTAL_ML[MQTT_TOPIC_LEN] = "hydrodozerpump/hydrodozerpump/scheduller/total_ml";
    char MQTT_TOPIC_SCHEDULLER_PART_A_PCT[MQTT_TOPIC_LEN] = "hydrodozerpump/hydrodozerpump/scheduller/part_a_pct";
    char MQTT_TOPIC_SCHEDULLER_PART_B_PCT[MQTT_TOPIC_LEN] = "hydrodozerpump/hydrodozerpump/scheduller/part_b_pct";
    char MQTT_TOPIC_SCHEDULLER_PAUSE[MQTT_TOPIC_LEN] = "hydrodozerpump/hydrodozerpump/scheduller/pause";
    char MQTT_TOPIC_LOW_BOTTLE_ALARM_PCT[MQTT_TOPIC_LEN] = "hydrodozerpump/hydrodozerpump/alarm/low_bottle_pct";
    const char* PUMP_RUN_LOG_CSV_PATH = "/pump_runs.csv";
    const size_t PUMP_RUN_LOG_MAX_BYTES = 102400; // 100 KB

    // ---------- Status LEDs ----------
    const uint8_t STATUS_LED_GREEN_PIN = D6; // GPIO12
    const uint8_t STATUS_LED_RED_PIN = D7;   // GPIO13
    const bool STATUS_LED_ACTIVE_HIGH = true;
    const unsigned long STATUS_LED_ALT_INTERVAL_MS = 350UL;
    const unsigned long STATUS_LED_PULSE_PERIOD_MS = 1600UL;
    const uint16_t STATUS_LED_PWM_MAX = 1023U;
    const uint16_t STATUS_LED_PWM_MIN = 160U;

    // ---------- Pump Pins (ESP8266 D pins) ----------
    const uint8_t PUMP1_PIN = D1; // GPIO5
    const uint8_t PUMP2_PIN = D2; // GPIO4
    const uint8_t FACTORY_RESET_PIN = D5; // GPIO14, short to GND at boot to trigger reset
    // If ULN2003 turns ON when GPIO is HIGH, keep this true.
    // If your wiring is inverted, set to false.
    const bool PUMP_ACTIVE_HIGH = true;
    // Hard safety cutoff (milliseconds)
    const unsigned long PUMP_HARD_MAX_MS = 120000; // 120s
    const unsigned long CAL_RUN_DURATION_MS = 60000; // fixed 60s calibration run
    const unsigned long FACTORY_RESET_HOLD_MS = 3000; // hold jumper for 3s
    const float CAL_MIN_FLOW_ML_PER_SEC = 0.001f;
    const float CAL_MAX_FLOW_ML_PER_SEC = 50.0f;
    struct PumpState
        {
        bool running;
        unsigned long startedAt;
        unsigned long maxRunMs;
        };
    PumpState pump1 = {false, 0, 0};
    PumpState pump2 = {false, 0, 0};
    bool calibrationAwaitResult[3] = {false, false, false}; // index 1..2 used
    float haDoseMl[3] = {0.0f, 5.0f, 5.0f}; // index 1..2 used for HA dose controls
    // Scheduller controls (kept independent from immediate dose_now execution).
    float schedullerTotalMl = 100.0f;
    float schedullerPartAPct = 50.0f;
    float schedullerPartBPct = 50.0f;
    bool schedullerPaused = false;
    float lowBottleAlarmPct = 10.0f;
    int schedullerHour1 = 8;
    int schedullerHour2 = 14;
    int schedullerHour3 = 20;
    // Per-job run history (slot 1..3, pump 1..2 => 6 jobs total).
    // Stored as (year, yday) to survive reboot and skip same-day duplicate runs.
    int schedullerLastRunYear[4][3] = {
        {-1, -1, -1},
        {-1, -1, -1},
        {-1, -1, -1},
        {-1, -1, -1}
    };
    int schedullerLastRunYDay[4][3] = {
        {-1, -1, -1},
        {-1, -1, -1},
        {-1, -1, -1},
        {-1, -1, -1}
    };
    time_t schedullerLastAttemptEpoch[4] = {0, 0, 0, 0}; // index 1..3 used
    const unsigned long SCHEDULLER_PUMP_SWITCH_GAP_MS = 10000UL; // 10s gap between Pump 1 and Pump 2
    struct SchedullerPump2Sequence
    {
        bool pending;
        bool gapStarted;
        uint8_t slot;
        unsigned long durationMs;
        float requestedMl;
        unsigned long gapStartedAtMs;
        int runYear;
        int runYDay;
    };
    SchedullerPump2Sequence schedullerPump2Sequence = {false, false, 0, 0, 0.0f, 0, -1, -1};




// ---------- Global objects ----------
WiFiManager wm;
ESP8266WebServer server(80);
WiFiClient espClient;
PubSubClient mqttClient(espClient);
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
void loop()
{
    unsigned long now = millis();
    uint32_t heapNow = ESP.getFreeHeap();
    if (heapNow < minFreeHeap)
        minFreeHeap = heapNow;

    if (isIntervalElapsed(now, &lastTelemetryTick, telemetryInterval))
    {
        lastTelemetryTick = now;
        printHealth();
    }

    if (isIntervalElapsed(now, &lastAutoPublish, autoPublishInterval))
    {
        lastAutoPublish = now;
        requestAutoStatePublish(0);
    }

    // pump loop
    pumpsUpdateSafety();
    updateStatusLeds();

    //MQTT Loop
    ensureMQTT();
    mqttClient.loop();
    processTimeSync();
    processSchedullerPump2Sequence();
    processScheduller();
    processPendingHADiscoveryRepublish();
    processDeferredPublishes();

    // Networking
    server.handleClient();      // <-- REQUIRED
    MDNS.update();              // <-- REQUIRED on ESP8266

}


// ---------- WiFi ----------
// WiFiManager wm; //reference moved at the top

void setupWiFi()
{

    WiFi.setSleepMode(WIFI_NONE_SLEEP);  // Do not sleep

    if (networkUseDhcp)
    {
        WiFi.config(0U, 0U, 0U);
        Serial.println("[WIFI] IP mode: DHCP");
    }
    else
    {
        IPAddress ip, gw, mask, dns;
        bool ok = ip.fromString(networkIp) &&
                  gw.fromString(networkGateway) &&
                  mask.fromString(networkNetmask) &&
                  dns.fromString(networkDns);
        if (ok)
        {
            WiFi.config(ip, gw, mask, dns);
            Serial.println("[WIFI] IP mode: Manual");
        }
        else
        {
            Serial.println("[WIFI] Invalid manual network settings. Falling back to DHCP.");
            WiFi.config(0U, 0U, 0U);
            networkUseDhcp = true;
        }
    }

    wm.setHostname(deviceName);
    WiFi.hostname(deviceName);

    Serial.println();
    Serial.println("[WIFI] Starting WiFiManager");

    // Keep portal simple and reliable
    wm.setConfigPortalTimeout(180);   // 3 minutes
    wm.setConnectTimeout(20);          // seconds

    // Option A behavior:
    // Try saved WiFi, otherwise start captive portal automatically
    bool connected = wm.autoConnect("HydroDozerPump-Setup");

    if (!connected)
    {
        Serial.println("[WIFI] Failed to connect, rebooting...");
        delay(2000);
        ESP.restart();
    }

    // Connected successfully
    Serial.println("[WIFI] Connected!");
    Serial.print("[WIFI] SSID: ");
    Serial.println(WiFi.SSID());

    Serial.print("[WIFI] IP: ");
    Serial.println(WiFi.localIP());

    Serial.print("[WIFI] RSSI: ");
    Serial.print(WiFi.RSSI());
    Serial.println(" dBm");

    if (MDNS.begin(deviceName))
    {
    Serial.println("[MDNS] Responder started");
    Serial.print("[MDNS] http://");
    Serial.print(deviceName);
    Serial.println(".local");
    } else
    {
    Serial.println("[MDNS] Failed to start");
    }

}

bool hasValidSystemTime()
{
    time_t now = time(nullptr);
    return (now >= TIME_VALID_AFTER_EPOCH);
}

bool isValidTimeZoneSpec(const String& tzSpec)
{
    if (tzSpec.length() == 0 || tzSpec.length() >= TIMEZONE_LEN)
        return false;

    for (size_t i = 0; i < tzSpec.length(); i++)
    {
        char c = tzSpec.charAt(i);
        if (c < 32 || c > 126)
            return false;
    }

    return true;
}

void applyTimeZone()
{
    setenv("TZ", timeZoneSpec, 1);
    tzset();
    appendDebugLog("TIME zone applied tz=%s", timeZoneSpec);
}

void requestTimeSync(const char* reason)
{
    if (!WiFi.isConnected())
    {
        nextTimeSyncAt = millis() + TIME_SYNC_RETRY_MS;
        appendDebugLog("TIME sync deferred reason=%s (wifi disconnected)", reason ? reason : "unknown");
        return;
    }

    // Use TZ-aware API so localtime()/strftime(%Z) follows the configured POSIX TZ string.
    configTime(timeZoneSpec, NTP_SERVER_PRIMARY, NTP_SERVER_SECONDARY);
    nextTimeSyncAt = millis() + TIME_SYNC_INTERVAL_MS;

    Serial.print("[TIME] Sync requested: ");
    Serial.println(reason ? reason : "periodic");
    appendDebugLog("TIME sync requested reason=%s next_in_ms=%lu", reason ? reason : "periodic", TIME_SYNC_INTERVAL_MS);
}

void setupTimeSync()
{
    applyTimeZone();
    nextTimeSyncAt = 0;
    requestTimeSync("boot");
}

void processTimeSync()
{
    unsigned long nowMs = millis();
    if ((long)(nowMs - nextTimeSyncAt) >= 0)
    {
        requestTimeSync("12h");
    }

    bool validNow = hasValidSystemTime();
    if (validNow && !timeSyncHadValidTime)
    {
        timeSyncHadValidTime = true;
        time_t now = time(nullptr);
        Serial.print("[TIME] Time acquired, epoch=");
        Serial.println((unsigned long)now);
        appendDebugLog("TIME acquired epoch=%lu", (unsigned long)now);
        if (bootLogPending)
        {
            appendPumpLogEventCsv("System boot");
            bootLogPending = false;
        }
    }
    else if (!validNow)
    {
        timeSyncHadValidTime = false;
    }
}

bool runSchedullerDoseForSlot(uint8_t slot, int year, int yday)
{
    if (slot < 1 || slot > 3)
        return false;

    float doseEachMl = schedullerTotalMl / 3.0f;
    if (doseEachMl <= 0.0f)
        return false;

    float dosePartAMl = (doseEachMl * schedullerPartAPct) / 100.0f;
    if (dosePartAMl < 0.0f) dosePartAMl = 0.0f;
    if (dosePartAMl > doseEachMl) dosePartAMl = doseEachMl;
    float dosePartBMl = doseEachMl - dosePartAMl;
    if (dosePartBMl < 0.0f) dosePartBMl = 0.0f;

    bool runPump1 = (dosePartAMl > 0.0f);
    bool runPump2 = (dosePartBMl > 0.0f);

    // Persisted per-job history prevents same-day duplicate runs after reboot.
    if (runPump1 && hasSchedullerJobRunToday(slot, 1, year, yday))
        runPump1 = false;
    if (runPump2 && hasSchedullerJobRunToday(slot, 2, year, yday))
        runPump2 = false;

    if (!runPump1 && !runPump2)
        return false;

    unsigned long duration1 = 0;
    unsigned long duration2 = 0;
    const char* reason = "invalid";

    if (runPump1 && !computeDoseDurationMs(1, dosePartAMl, &duration1, &reason))
    {
        publishDosePermission(1, dosePartAMl, false, reason);
        appendDebugLog("SCHED slot=%u pump=1 reject reason=%s", slot, reason);
        return false;
    }
    if (runPump2 && !computeDoseDurationMs(2, dosePartBMl, &duration2, &reason))
    {
        publishDosePermission(2, dosePartBMl, false, reason);
        appendDebugLog("SCHED slot=%u pump=2 reject reason=%s", slot, reason);
        return false;
    }

    if (runPump1)
    {
        float req1 = dosePartAMl;
        if (!checkPumpRunPermission(1, duration1, &req1, &reason))
        {
            publishDosePermission(1, req1, false, reason);
            appendDebugLog("SCHED slot=%u pump=1 blocked reason=%s", slot, reason);
            return false;
        }
    }
    if (runPump2)
    {
        float req2 = dosePartBMl;
        if (!checkPumpRunPermission(2, duration2, &req2, &reason))
        {
            publishDosePermission(2, req2, false, reason);
            appendDebugLog("SCHED slot=%u pump=2 blocked reason=%s", slot, reason);
            return false;
        }
    }

    if (runPump1)
    {
        pumpStart(1, duration1);
        if (!isPumpRunning(1))
        {
            publishDosePermission(1, dosePartAMl, false, "start_failed");
            appendDebugLog("SCHED slot=%u pump=1 start_failed", slot);
            return false;
        }
        publishDosePermission(1, dosePartAMl, true, "ok");
        markSchedullerJobRunToday(slot, 1, year, yday);
    }
    if (runPump2 && !runPump1)
    {
        pumpStart(2, duration2);
        if (!isPumpRunning(2))
        {
            publishDosePermission(2, dosePartBMl, false, "start_failed");
            appendDebugLog("SCHED slot=%u pump=2 start_failed", slot);
            return false;
        }
        publishDosePermission(2, dosePartBMl, true, "ok");
        markSchedullerJobRunToday(slot, 2, year, yday);
    }
    else if (runPump1 && runPump2)
    {
        // Scheduler path is sequential: Pump 1 runs first, then Pump 2 after a fixed gap.
        schedullerPump2Sequence.pending = true;
        schedullerPump2Sequence.gapStarted = false;
        schedullerPump2Sequence.slot = slot;
        schedullerPump2Sequence.durationMs = duration2;
        schedullerPump2Sequence.requestedMl = dosePartBMl;
        schedullerPump2Sequence.gapStartedAtMs = 0;
        schedullerPump2Sequence.runYear = year;
        schedullerPump2Sequence.runYDay = yday;
        publishDosePermission(2, dosePartBMl, true, "queued");
        appendDebugLog("SCHED slot=%u pump=2 queued after pump=1", slot);
    }

    requestAutoStatePublish(100);
    if (mqttClient.connected())
        publishCmdAck(true, "scheduller_dose", "started");
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

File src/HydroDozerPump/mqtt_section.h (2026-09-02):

static void formatIpAddress(const IPAddress& ip, char* out, size_t outLen)
{
    if (outLen == 0)
        return;
    snprintf(out, outLen, "%u.%u.%u.%u", ip[0], ip[1], ip[2], ip[3]);
}

void setupMQTT() // MQTT Publish
{
    mqttClient.setServer(mqttBroker, mqttPort);
    mqttClient.setKeepAlive(60);
    mqttClient.setCallback(mqttCallback);
}

void ensureMQTT() // MQTT Connect
{
    if (mqttClient.connected())
        return;

    unsigned long now = millis();

    if (now - lastMQTTAttempt < mqttInterval)
        return;

    lastMQTTAttempt = now;

    Serial.println("[MQTT] Attempting connection...");

    if (mqttClient.connect(
        mqttClientId,
        mqttUser,
        mqttPass,
        MQTT_TOPIC_AVAIL,
        1,
        true,
        "offline")) // Last Will
    {
        Serial.println("[MQTT] Connected!");
        mqttReconnectCount++;

        mqttClient.publish(MQTT_TOPIC_AVAIL, "online", true);

        mqttClient.subscribe(MQTT_TOPIC_CMD);
        mqttClient.subscribe(MQTT_TOPIC_HA_CMD);
        mqttClient.subscribe(MQTT_TOPIC_HA_STATUS);
        publishSystemState();
        requestHADiscoveryPublish(250);
        requestAutoStatePublish(500);
        requestAllRetainedStatePublish();
        printHealth();

        Serial.println("[MQTT] Subscribed to CMD topic");

    }
    else
    {
        Serial.print("[MQTT] Failed, rc=");
        Serial.println(mqttClient.state());
    }
}

void printHealth() // MQTT refresh
{
    uint32_t heap = ESP.getFreeHeap();
    uint8_t frag = ESP.getHeapFragmentation();
    uint32_t maxBlock = ESP.getMaxFreeBlockSize();
    if (heap < minFreeHeap)
        minFreeHeap = heap;

    Serial.print("[HEALTH] Free heap: ");
    Serial.println(heap);

    if (mqttClient.connected())
    {
        StaticJsonDocument<320> doc;
        char ipBuf[16];
        formatIpAddress(WiFi.localIP(), ipBuf, sizeof(ipBuf));
        doc["uptime_s"] = millis() / 1000UL;
        doc["wifi"] = WiFi.isConnected();
        doc["ip"] = ipBuf;
        doc["rssi"] = WiFi.RSSI();
        doc["heap"] = heap;
        doc["min_heap"] = minFreeHeap;
        doc["heap_frag"] = frag;
        doc["max_free_block"] = maxBlock;
        doc["mqtt_reconnects"] = mqttReconnectCount;

        char payload[320];
        serializeJson(doc, payload, sizeof(payload));
        mqttClient.publish(MQTT_TOPIC_HEALTH, payload, true);
    }
}

// MQTT mapping (HA bottle state source for capacity/name/percent displays)
// State topic (retained): hydrodozerpump/bottle/<bottleId>/state
// Published JSON: {"id":X,"name":"...","remaining_ml":...,"capacity_ml":...,"percent":...}
// Related commands consumed in mqttCallback():
// - hydrodozerpump/ha/cmd: {"ha":"set_capacity","bottle":<id>,"ml":<float>}
// - hydrodozerpump/cmd: {"bottle":<id>,"refill":true}
void publishBottleState(uint8_t bottleId)
{
    if (!mqttClient.connected() || bottleId < 1 || bottleId > 2)
        return;

    float percent = 0.0f;
    if (bottles[bottleId].capacity_ml > 0.0f)
        percent = (bottles[bottleId].remaining_ml / bottles[bottleId].capacity_ml) * 100.0f;

    if (percent < 0.0f) percent = 0.0f;
    if (percent > 100.0f) percent = 100.0f;

    char topic[64];
    snprintf(topic, sizeof(topic), MQTT_TOPIC_BOTTLE_STATE_FMT, bottleId);

    StaticJsonDocument<192> doc;
    doc["id"] = bottleId;
    doc["name"] = bottleLabelById(bottleId);
    doc["remaining_ml"] = bottles[bottleId].remaining_ml;
    doc["capacity_ml"] = bottles[bottleId].capacity_ml;
    doc["percent"] = percent;

    char payload[192];
    serializeJson(doc, payload, sizeof(payload));
    mqttClient.publish(topic, payload, true);
}

void publishAllBottleStates()
{
    publishBottleState(1);
    publishBottleState(2);
}

// MQTT mapping (HA Number: "Pump X Dose mL")
// State topic (retained): hydrodozerpump/pump/<pumpId>/dose_ml
// Published payload: decimal string in mL (example: "25.00")
// Related command consumed in mqttCallback():
// - hydrodozerpump/ha/cmd: {"ha":"set_dose_ml","pump":<id>,"ml":<float>}
void publishPumpDoseMlState(uint8_t pumpId)
{
    if (!mqttClient.connected() || pumpId < 1 || pumpId > 2)
        return;

    char topic[64];
    snprintf(topic, sizeof(topic), MQTT_TOPIC_PUMP_DOSE_ML_FMT, pumpId);

    char payload[16];
    dtostrf(haDoseMl[pumpId], 0, 2, payload);
    mqttClient.publish(topic, payload, true);
}

void publishAllPumpDoseMlStates()
{
    publishPumpDoseMlState(1);
    publishPumpDoseMlState(2);
}

void publishLowBottleAlarmState()
{
    if (!mqttClient.connected())
        return;

    char payload[8];
    snprintf(payload, sizeof(payload), "%u", (unsigned int)(lowBottleAlarmPct + 0.5f));
    mqttClient.publish(MQTT_TOPIC_LOW_BOTTLE_ALARM_PCT, payload, true);
}

// MQTT mapping (HA Number controls in Scheduller section)
// State topics (retained):
// - hydrodozerpump/scheduller/total_ml
// - hydrodozerpump/scheduller/part_a_pct
// - hydrodozerpump/scheduller/part_b_pct
// - hydrodozerpump/scheduller/pause
// Related commands consumed in mqttCallback():
// - hydrodozerpump/ha/cmd: {"ha":"set_scheduller_total_ml","ml":<float>}
// - hydrodozerpump/ha/cmd: {"ha":"set_scheduller_part_a_pct","pct":<float>}
// - hydrodozerpump/ha/cmd: {"ha":"set_scheduller_part_b_pct","pct":<float>}
// - hydrodozerpump/ha/cmd: {"ha":"set_scheduller_pause","value":0|1}
void publishSchedullerState(uint8_t fieldId)
{
    if (!mqttClient.connected())
        return;

    const char* topic = nullptr;
    char payload[20];

    if (fieldId == 1)
    {
        topic = MQTT_TOPIC_SCHEDULLER_TOTAL_ML;
        dtostrf(schedullerTotalMl, 0, 2, payload);
    }
    else if (fieldId == 2)
    {
        topic = MQTT_TOPIC_SCHEDULLER_PART_A_PCT;
        dtostrf(schedullerPartAPct, 0, 1, payload);
    }
    else if (fieldId == 3)
    {
        topic = MQTT_TOPIC_SCHEDULLER_PART_B_PCT;
        dtostrf(schedullerPartBPct, 0, 1, payload);
    }
    else if (fieldId == 4)
    {
        topic = MQTT_TOPIC_SCHEDULLER_PAUSE;
        snprintf(payload, sizeof(payload), "%u", schedullerPaused ? 1U : 0U);
    }
    else
    {
        return;
    }

    mqttClient.publish(topic, payload, true);
}

void publishAllSchedullerStates()
{
    publishSchedullerState(1);
    publishSchedullerState(2);
    publishSchedullerState(3);
    publishSchedullerState(4);
}
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

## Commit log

2026-09-02 Initial public release
    [Enclosure_Box.3mf, Mounting_Logic_plate.3mf, Mounting_Pump_Plate.3mf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]
2026-09-02 Update BOM enclosure and capacitor references
2026-09-03 Add technical wiring drawing
2026-09-03 Document ULN2003 pin mappings
